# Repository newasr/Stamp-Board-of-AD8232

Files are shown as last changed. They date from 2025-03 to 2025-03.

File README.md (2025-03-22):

# AD8232 Stamp Board - PCB Design  

This repository contains the **KiCad v9** design files for a **compact AD8232 stamp board**, built according to **Figure 66** of the [AD8232 datasheet](https://www.analog.com/media/en/technical-documentation/data-sheets/ad8232.pdf).  

## Project Overview  
The **AD8232** is an integrated signal conditioning block designed for **ECG and biopotential measurement** applications. This project involves designing a **compact and manufacturable PCB** with the following key features:  

- **Compact Form Factor** – Optimized layout for minimal space usage  
- **Standardized Terminals** – VDD, GND, LO+, LO-, OUT, nSDN, LA, RA, RL  
- **Proper Grounding** – Copper pours on top and bottom layers for improved signal integrity  
- **Manufacturing-Ready** – Includes **Gerber files, BOM, and 3D visualization**  

## Files Included  
- **Schematic** – Circuit design of the AD8232 stamp board  
- **PCB Layout** – Optimized component placement and routing  
- **PCB Routing** – Defined traces and copper pours for signal integrity  
- **Gerber Files** – Ready for PCB fabrication  
- **Bill of Materials (BOM)** – Includes Digikey part numbers and component details  
- **3D Visualization** – Ensures proper component placement and alignment  

## Tools Used  
This project was developed using **KiCad v9**, an open-source EDA tool.  

### Custom Libraries  
- **myLibrary.kicad_sym** – Custom schematic symbols  
- **myLibrary.pretty** – Custom footprints and 3D models  

### Component Footprints  
- All **resistors, capacitors, inductors, and LEDs** use:  
  **0402_1005Metric**  

---

## Schematic  
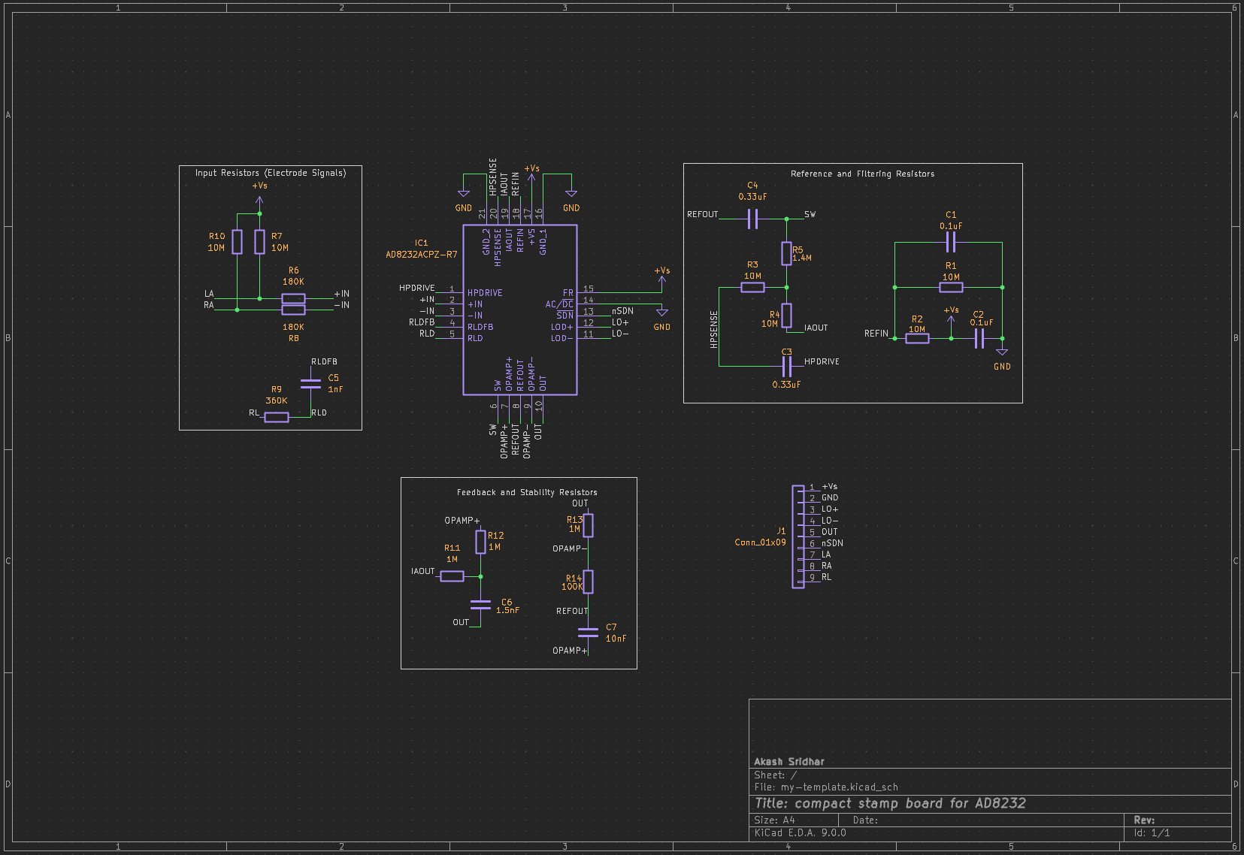
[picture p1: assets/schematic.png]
 

## PCB Layout  
### Component Placement  
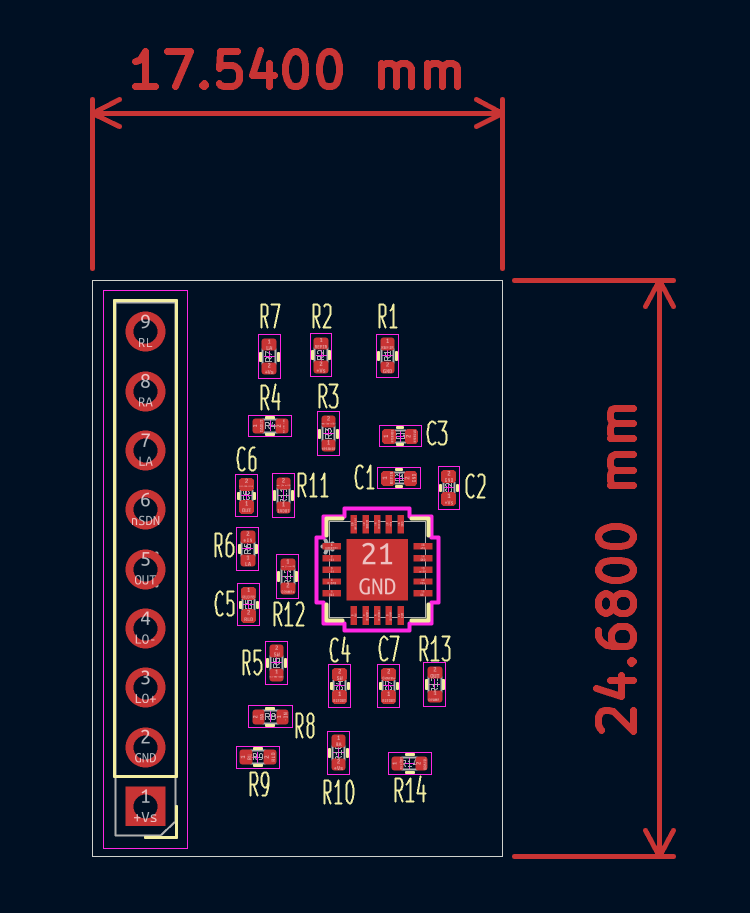
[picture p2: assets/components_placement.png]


### Overall Board Layout  
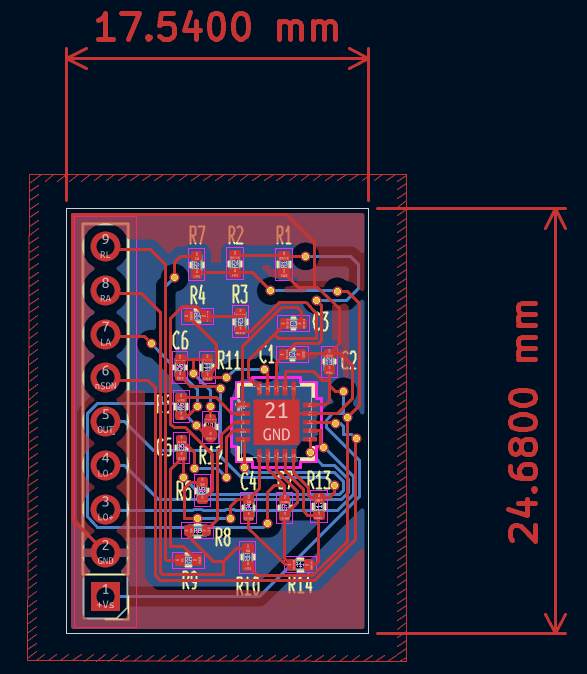
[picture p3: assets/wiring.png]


---

## 3D View  
### Top View  
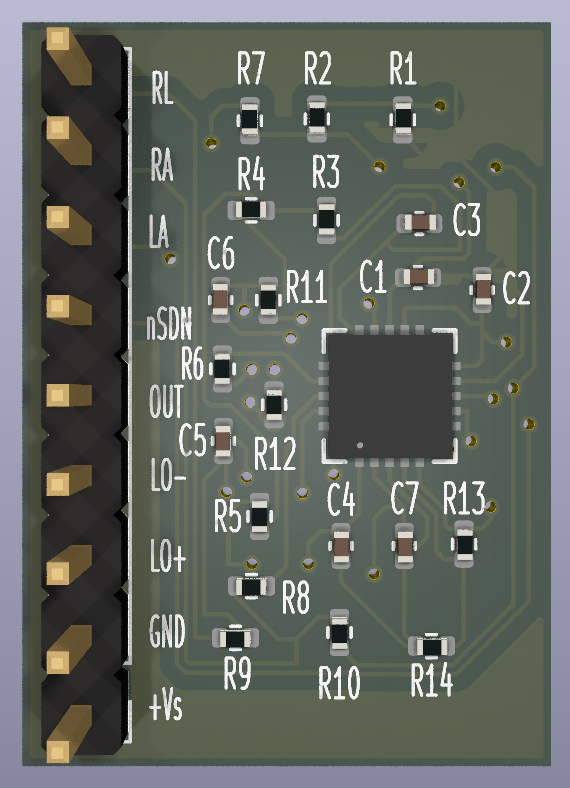
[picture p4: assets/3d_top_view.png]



### Bottom View  
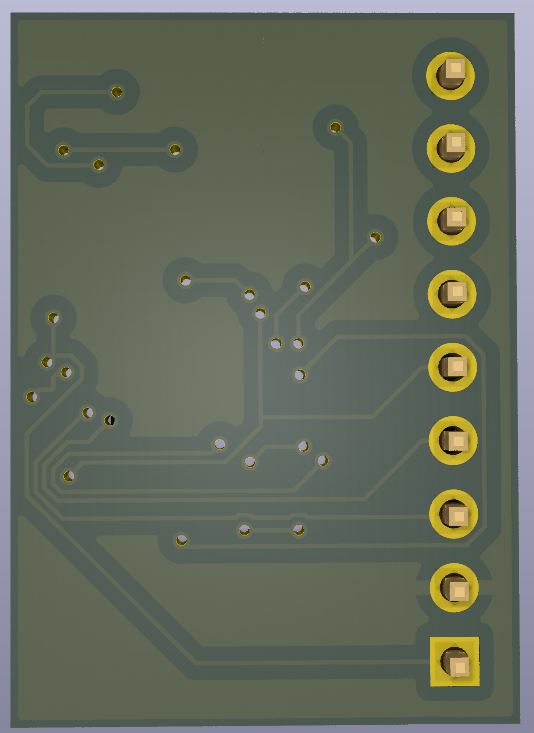
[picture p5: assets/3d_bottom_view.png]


---

## License  
This project is licensed under the **MIT License**. See the [LICENSE](LICENSE) file for details.  

## Contact  
Akash Sridhar – [GitHub](https://github.com/akashsridhar20)

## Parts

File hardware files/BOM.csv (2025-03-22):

Reference | Value | Footprint | Qty | Digikey Part# | Digikey URL
IC1 | AD8232ACPZ-R7 | myLibrary:CP_20_10_ADI | 1 | 505-AD8232ACPZ-R7CT-ND | https://www.digikey.in/en/products/detail/analog-devices-inc/AD8232ACPZ-R7/3758432
R14 | 100K | Resistor_SMD:R_0402_1005Metric | 1 | 311-100KLRTR-ND | https://www.digikey.in/en/products/detail/yageo/RC0402FR-07100KL/726526
R11,R12,R13 | 1M | Resistor_SMD:R_0402_1005Metric | 3 | A129663CT-ND | https://www.digikey.in/en/products/detail/te-connectivity-passive-product/CRGCQ0402F1M0/8576265
R9 | 360K | Resistor_SMD:R_0402_1005Metric | 1 | P360KLTR-ND | https://www.digikey.in/en/products/detail/panasonic-electronic-components/ERJ-2RKF3603X/1746207
R6,R8 | 180K | Resistor_SMD:R_0402_1005Metric | 2 | CR0402-FX-1803GLFCT-ND | https://www.digikey.in/en/products/detail/bourns-inc/CR0402-FX-1803GLF/3783200
R5 | 1.4M | Resistor_SMD:R_0402_1005Metric | 1 | RMCF0402FT1M40TR-ND | https://www.digikey.in/en/products/detail/stackpole-electronics-inc/RMCF0402FT1M40/1714344
R1,R2,R3,R4,R7,R10 | 10M | Resistor_SMD:R_0402_1005Metric | 6 | 541-10.0MLCT-ND | https://www.digikey.in/en/products/detail/vishay-dale/CRCW040210M0FKED/1178433
J1 | Conn_01x09 | Connector_PinHeader_2.54mm:PinHeader_1x09_P2.54mm_Vertical | 1
C7 | 10nF | Capacitor_SMD:C_0402_1005Metric | 1 | 478-KGM05AR70J103KHTR-ND | https://www.digikey.in/en/products/detail/kyocera-avx/KGM05AR70J103KH/1597637
C6 | 1.5nF | Capacitor_SMD:C_0402_1005Metric | 1 | 478-KGM05AR70J152KHTR-ND | https://www.digikey.in/en/products/detail/kyocera-avx/KGM05AR70J152KH/3080050
C5 | 1nF | Capacitor_SMD:C_0402_1005Metric | 1 | 399-C0402C102K9RACTUTR-ND | https://www.digikey.in/en/products/detail/kemet/C0402C102K9RACTU/2196206
C3,C4 | 0.33uF | Capacitor_SMD:C_0402_1005Metric | 2 | 445-172465-2-ND | https://www.digikey.in/en/products/detail/tdk-corporation/C1005X6S0G334K050BB/4989840
C1,C2 | 0.1uF | Capacitor_SMD:C_0402_1005Metric | 2 | 399-14871-2-ND | https://www.digikey.in/en/products/detail/kemet/C0402C104K7PACTU/7381987

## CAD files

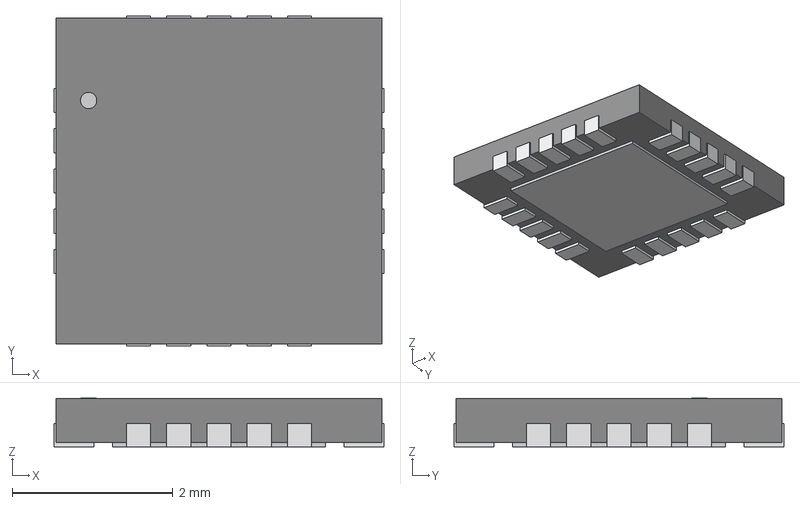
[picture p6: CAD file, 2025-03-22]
hardware files/3d/CP_20_10_ADI.step
4.10 x 4.10 x 0.603 mm

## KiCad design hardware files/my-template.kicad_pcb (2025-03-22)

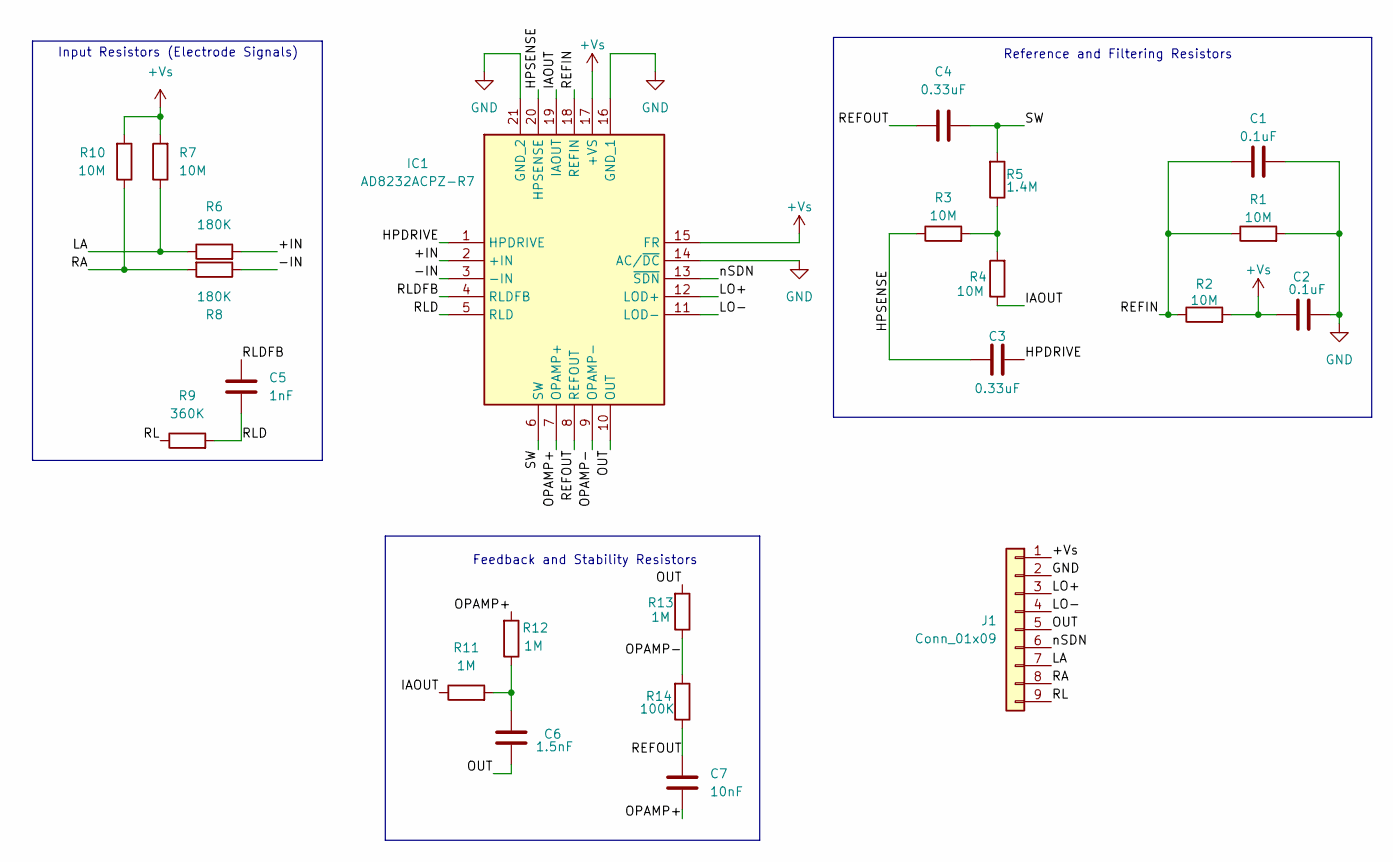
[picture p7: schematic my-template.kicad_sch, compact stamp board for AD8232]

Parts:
C1, C2: 0.1uF; C_0402_1005Metric; Digikey Part# 399-14871-2-ND
C3, C4: 0.33uF; C_0402_1005Metric; Digikey Part# 445-172465-2-ND
C5: 1nF; C_0402_1005Metric; Digikey Part# 399-C0402C102K9RACTUTR-ND
C6: 1.5nF; C_0402_1005Metric; Digikey Part# 478-KGM05AR70J152KHTR-ND
C7: 10nF; C_0402_1005Metric; Digikey Part# 478-KGM05AR70J103KHTR-ND
IC1: AD8232ACPZ-R7; CP_20_10_ADI; Mouser Part Number 584-AD8232ACPZ-R7
J1: Conn_01x09; PinHeader_1x09_P2.54mm_Vertical
R1, R2, R3, R4, R7, R10: 10M; R_0402_1005Metric; Digikey Part# 541-10.0MLCT-ND
R5: 1.4M; R_0402_1005Metric; Digikey Part# RMCF0402FT1M40TR-ND
R6, R8: 180K; R_0402_1005Metric; Digikey Part# CR0402-FX-1803GLFCT-ND
R9: 360K; R_0402_1005Metric; Digikey Part# P360KLTR-ND
R11, R12, R13: 1M; R_0402_1005Metric; Digikey Part# A129663CT-ND
R14: 100K; R_0402_1005Metric; Digikey Part# 311-100KLRTR-ND

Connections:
+Vs: C2.1, IC1.15 (FR), IC1.17 (+VS), J1.1, R2.2, R7.2, R10.2
/+IN: IC1.2 (+IN), R6.2
/-IN: IC1.3 (-IN), R8.1
/HPDRIVE: C3.2, IC1.1 (HPDRIVE)
/HPSENSE: C3.1, IC1.20 (HPSENSE), R3.1
/IAOUT: IC1.19 (IAOUT), R4.1, R11.1
/LA: J1.7, R6.1, R7.1
/LO+: IC1.12 (LOD+), J1.3
/LO-: IC1.11 (LOD-), J1.4
/OPAMP+: C7.2, IC1.7 (OPAMP+), R12.2
/OPAMP-: IC1.9 (OPAMP-), R13.1, R14.2
/OUT: C6.1, IC1.10 (OUT), J1.5, R13.2
/RA: J1.8, R8.2, R10.1
/REFIN: C1.1, IC1.18 (REFIN), R1.1, R2.1
/REFOUT: C4.1, C7.1, IC1.8 (REFOUT), R14.1
/RL: J1.9, R9.1
/RLD: C5.2, IC1.5 (RLD), R9.2
/RLDFB: C5.1, IC1.4 (RLDFB)
/SW: C4.2, IC1.6 (SW), R5.2
/nSDN: IC1.13 (~SDN), J1.6
GND: C1.2, C2.2, IC1.14 (AC/~DC), IC1.16 (GND_1), IC1.21 (GND_2), J1.2, R1.2
unnamed: C6.2, R11.2, R12.1
unnamed: R3.2, R4.2, R5.1

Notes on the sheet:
Feedback and Stability Resistors
Input Resistors (Electrode Signals)
Reference and Filtering Resistors

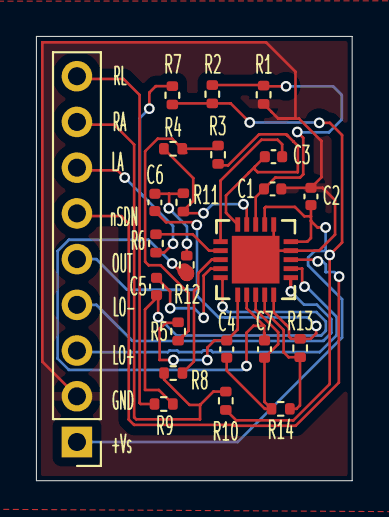
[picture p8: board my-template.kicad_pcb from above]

Board: 2 copper layers, 17.5 x 24.7 mm, 23 parts (0 on the bottom side), 23 nets.

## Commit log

2025-03-22 added images of pcb, schematic
2025-03-22 added bom and 3d models
    [BOM.csv, CP_20_10_ADI.step]
2025-03-22 added gerber and its zip
2025-03-22 added hardware files
    [my-template.kicad_pcb, my-template.kicad_sch]
2025-03-22 organised hardware files
    [BOM.csv, CP_20_10_ADI.step, my-template.kicad_pcb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]
2025-03-22 update labels in pcb
    [my-template.kicad_pcb]
